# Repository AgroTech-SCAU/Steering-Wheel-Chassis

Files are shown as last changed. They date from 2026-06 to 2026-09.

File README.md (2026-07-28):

<div align="center">

# Steering-Wheel-Chassis

</div>

> AgroTech 协会中型轮式机器人代码仓库  

> 本仓库用于统一管理协会内部中型轮式机器人平台的嵌入式电控代码、Pi 端底盘通信桥、ROS2 导航系统与后续视觉 / 任务编排代码  

> 机械模型已拆分到独立仓库维护，当前仓库按“一车一目录”组织，每个一级目录代表一辆独立机器人平台，便于按车型迭代、按平台维护、按任务复用

---

## 1. 仓库定位

- 面向 AgroTech 协会中型轮式机器人平台的统一代码仓库
- 当前主要包含底盘 MCU 控制代码、Pi 端通信桥、ROS2 导航定位系统、雷达驱动、仿真与启动文件
- 适合用于舵轮底盘、五自由度机械臂、导航定位、任务状态机等整车软件链路的协同开发
- 机械模型统一维护在 [`AgroTech-SCAU/Steering-Wheel-Chassis-Model-Collection`](https://github.com/AgroTech-SCAU/Steering-Wheel-Chassis-Model-Collection)

---

## 2. 当前包含的机器人

| 机器人 | 状态 | 简介 |
| --- | --- | --- |
| `SteerWheel Mk.1` | 开发中 / 原型验证 | 初代原型机，用于验证舵轮底盘、机械臂集成、电控架构与控制算法 |
| `Atlas` | 开发中 / 导航与底盘联调 | 新一代舵轮底盘平台，当前包含 MCU 底盘控制代码、Pi 端通信桥和 ROS2 导航系统 |

另有一台尚未命名的轮式机器人正在规划中，同样采用舵轮底盘与五轴五自由度机械臂，后续会在仓库中以独立文件夹形式加入

---

## 3. 目录结构

```text
.
├─ Atlas/
│  ├─ chassis_control_code/   # MCU 端底盘控制代码，烧录到 STM32 控制板
│  ├─ chassis-pi-ws/          # 树莓派 5 ROS2 工作区，负责 MCU 通信桥接
│  ├─ navigation_system/      # ROS2 导航系统，包含雷达驱动、建图、定位、Nav2 与启动文件
│  └─ README.md
├─ SteerWheel Mk.1/
│  ├─ chassis_control_code/   # STM32H7 底盘 / 机械臂嵌入式控制代码
│  └─ README.md
└─ README.md
```

---

## 4. `SteerWheel Mk.1` 简介

`SteerWheel Mk.1` 是本仓库较早期的原型平台，主要承担以下任务：

- 验证四舵轮底盘的机械结构与运动学控制
- 验证底盘与五自由度机械臂的一体化集成
- 验证自研 STM32H723 控制板的软件分层与设备驱动架构
- 为后续 `Atlas` 及其他轮式机器人积累电控和软件复用资产

其目录中当前主要包含：

- 基于 STM32H723 的底盘与机械臂控制固件
- 机械臂 `URDF`、`mesh`、`launch` 等开发相关资源

机器人机械模型请前往独立仓库查看：

- [`AgroTech-SCAU/Steering-Wheel-Chassis-Model-Collection`](https://github.com/AgroTech-SCAU/Steering-Wheel-Chassis-Model-Collection)

更详细的说明请见 [SteerWheel Mk.1/README.md](./SteerWheel%20Mk.1/README.md)

---

## 5. `Atlas` 简介

`Atlas` 是当前重点推进的新一代中型轮式机器人平台，采用舵轮底盘作为移动底盘，使用 STM32 控制板完成底层实时控制，使用树莓派 5 运行 ROS2 Humble 导航系统

当前 `Atlas` 已经包含三部分：

- `chassis_control_code`：MCU 端底盘控制代码，负责底盘运动控制、IMU / odom 数据组织、Pi 通信协议收发与状态机权限判断
- `chassis-pi-ws`：Pi 端 ROS2 通信桥，负责读取 MCU 的 IMU / ODOM 数据并发布 `/odom`、`/imu` 和 TF，同时订阅 `/motor_cmd_vel` 并下发 `PI_CONTROL`
- `navigation_system`：ROS2 导航系统，包含 LSLIDAR 驱动、URDF、Gazebo、Cartographer 建图 / 纯定位、Nav2 与总启动文件

`Atlas` 的运行目标是形成如下闭环：

```text
MCU 底盘控制程序
  ↓ MCU_IMU / MCU_ODOM
chassis-pi-ws
  ↓ /odom /imu /tf
navigation_system
  ↓ /cmd_vel
competition_fsm
  ↓ /motor_cmd_vel
chassis-pi-ws
  ↓ PI_CONTROL
MCU 底盘控制程序
```

更详细的说明请见 [Atlas/README.md](./Atlas/README.md)

---

## 6. 开发路线

### 6.1 已有内容

- 舵轮底盘 MCU 控制代码
- Pi 端 ROS2 通信桥
- IMU / ODOM 二进制协议解析
- `/odom`、`/imu` 与 `odom -> base_footprint` TF 发布
- `/motor_cmd_vel` 到 MCU `PI_CONTROL` 的速度下发链路
- ROS2 Humble 导航系统
- Cartographer 2D 建图与纯定位
- Nav2 全局规划与局部控制
- LSLIDAR N10P 雷达驱动
- Gazebo 仿真启动文件

### 6.2 计划加入

- 更完整的 `competition_fsm` 与 `mission_manager` 说明
- `mcu_comm_bridge` 与 `robot_startup` 的统一启动入口
- `/mcu/status` 状态话题或诊断信息
- 真实场地地图与定位配置
- 视觉感知节点
- 机械臂上层控制接口
- 系统级联调记录与故障排查文档

---

## 7. 面向协作者的建议

- 新车型请直接以一级目录形式加入，保持“一车一目录”
- 机械、电控、ROS、仿真和任务代码建议按职责拆分维护，避免单个包承担过多功能
- MCU 端、Pi 端和导航端的接口应优先通过协议文档、README 和 launch 参数保持一致
- 涉及底盘安全的接口应区分周期性 topic、一次性 service 和长期 action，避免控制语义混乱
- 合并新功能前建议至少验证 `/odom`、`/imu`、`/scan`、`/motor_cmd_vel`、TF 树和 MCU AutoPi 执行链路

---

## 8. TODO

- [ ] 完善 `Atlas/README.md` 中真实地图、串口设备、启动参数和联调流程
- [ ] 将 `chassis-pi-ws` 的 `mcu_comm_bridge` 纳入 `navigation_system/robot_startup` 的真机总启动链路
- [ ] 补充或确认 `competition_fsm`、`mission_manager` 的源码位置、接口和启动方式
- [ ] 补充 `/mcu/status` 话题或诊断接口，方便状态机读取 MCU ready / fault / estop 状态
- [ ] 修正或补齐 `at_nav2` 真机定位所需的 `map.pbstream`、`map.yaml` 和 RViz 配置
- [ ] 给 URDF 补充 `imu_link` 及其相对 `base_link` 的固定变换
- [ ] 完善 MCU 固件编译、烧录、协议版本和调试说明
- [ ] 补充真实场地导航联调记录、常见问题和验收 checklist

---

## 9. 说明

本仓库仍处于持续开发阶段，部分车型资料、启动链路、接口文档和任务代码仍可能随项目推进调整

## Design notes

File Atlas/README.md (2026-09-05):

# Atlas

Atlas 是 AgroTech 协会的中型轮式机器人平台；这个目录统一管理整车 MCU 控制程序、Pi 端 ROS2 自主任务工作区、PC 主臂遥操作 App、ASRPro 语音链路和整车通信协议文档

当前主线是智械争锋全自主区：MCU 侧触发 AutoPi，Pi 端运行 YASMIN 比赛状态机，完成 A/B 场地识别、语义导航、视觉抓取、园区放置和 DONE/FAIL 上报

## Quick Start

下面的命令按实际设备划分：`chassis-pc-ws` 只在遥操作 PC 上运行，`chassis-pi-ws` 只在树莓派的 Ubuntu 22.04 / ROS2 Humble 环境运行；不要在 PC 上用 Pi 工作区能否启动来判断树莓派部署是否完整

本 Quick Start 是从未完成的实车配置走到整场联调的执行清单，不表示仓库默认 YAML 已可直接参赛；地图、导航点、扫描位姿、ROI 和放置位姿都需要按第 5～7 步实测填写

### 1. 整车角色分工

| 端 | 目录 | 作用 |
|---|---|---|
| MCU | `chassis_control_code/` | 底盘实时控制、机械臂执行、AutoPi 状态、安全边界和串口协议 |
| Pi | `chassis-pi-ws/` | ROS2 Humble、MCU bridge、导航、视觉、YASMIN 比赛状态机 |
| PC | `chassis-pc-ws/` | 主臂遥操作和上位机调试 |
| ASRPro | `atlas_asrpro/` | 语音触发和播报相关链路 |

正式自主比赛入口在 Pi 端：

```text
Atlas/chassis-pi-ws/src/app/atlas_competition_bringup/config/competition.yaml
Atlas/chassis-pi-ws/src/app/atlas_competition_bringup/launch/competition_stack.launch.py
```

### 2. MCU 侧准备

MCU 工程位于：

```text
Atlas/chassis_control_code/
```

使用 STM32CubeMX、EIDE 或当前工程配置的工具链编译烧录上电后先确认：

- MCU 固件已烧录
- Pi 可以打开 MCU 串口，例如 `/dev/ttyACM0`、`/dev/ttyUSB0` 或固定软链接 `/dev/mcu_uart`
- MCU 能输出状态、里程计、IMU 和机械臂状态帧
- AutoPi 由 MCU 侧条件触发，Pi 端不主动强行切换 MCU 模式

### 3. PC 遥操作准备

PC 端目录：

```text
Atlas/chassis-pc-ws/
```

安装 App 的 Python 依赖并从源码启动：

```bash
cd Atlas/chassis-pc-ws
python3 -m pip install -r requirements.txt
python3 scripts/main.py
```

App 启动后扫描串口，在界面中选择“主臂串口”和“从臂 MCU 串口”，应用配置后点击“开始运行”；已经打包时也可以直接启动 `AtlasTeleop`；PC 遥操作用于手动控制和调试，不是 Pi 自主比赛栈的入口；完整说明见 `chassis-pc-ws/README.md`

### 4. Pi 端环境和依赖

Pi 端目录：

```text
Atlas/chassis-pi-ws/
```

安装依赖：

```bash
sudo apt update
sudo apt install -y \
  python3-colcon-common-extensions \
  python3-pip \
  python3-rosdep \
  python3-yaml \
  python3-opencv \
  python3-numpy \
  ros-humble-navigation2 \
  ros-humble-nav2-bringup \
  ros-humble-cartographer \
  ros-humble-cartographer-ros \
  ros-humble-xacro \
  ros-humble-robot-state-publisher \
  ros-humble-rviz2
```

安装 ROS 包依赖和 Pi 端额外 Python 依赖：

全新系统如果还没有初始化 rosdep，先执行一次（已经初始化过则跳过 `rosdep init`）：

```bash
sudo rosdep init
rosdep update
```

如果 `src/third_lib/yasmin` 不存在，先取得当前工作区使用的 YASMIN 源码版本：

```bash
cd Atlas/chassis-pi-ws
mkdir -p src/third_lib
git clone https://github.com/uleroboticsgroup/yasmin.git src/third_lib/yasmin
git -C src/third_lib/yasmin checkout f28363379d9661e1c6048e304427488ee903be2c
```

```bash
cd Atlas/chassis-pi-ws
source /opt/ros/humble/setup.bash
rosdep install --from-paths src --ignore-src -r -y
python3 -m pip install --user -r requirements.txt
python3 -c "import onnxruntime; print(onnxruntime.__version__)"
test -f src/third_lib/yasmin/yasmin/package.xml
```

`vison_topic` 运行 ONNX 模型时直接导入 `onnxruntime`，该依赖没有可靠的 Humble rosdep 键，因此由工作区根目录的 `requirements.txt` 明确管理；比赛状态机还依赖固定版本的 YASMIN 源码；最后一条检查失败时，不要继续编译；依赖和配置准备完成后再执行第 8 步整包编译

### 5. 放入 A/B 半场地图

需要准备两套独立半场地图资源；导航 backend 会在视觉判断出 A/B 后，只启动对应半场的地图和定位栈

```text
arena_A.yaml
arena_A.pgm 或 arena_A.png
arena_A.pbstream

arena_B.yaml
arena_B.pgm 或 arena_B.png
arena_B.pbstream
```

地图可以放在仓库内，例如：

```text
Atlas/chassis-pi-ws/src/nav_system/at_nav2/maps/
```

也可以放在外部目录，然后在 `competition.yaml` 中使用绝对路径引用

### 6. 确认视觉和手眼标定

顶层 `competition.yaml` 管比赛场地、导航点、视觉扫描位姿、分拣 ROI 和放置位姿；相机内参和手眼矩阵属于 Pi 端视觉标定资产，当前由 `handeye_bridge` 单独加载：

```text
Atlas/chassis-pi-ws/src/vision_system/handeye_bridge/config/camera_intrinsics.yaml
Atlas/chassis-pi-ws/src/vision_system/handeye_bridge/config/samples_result.yaml
Atlas/chassis-pi-ws/src/vision_system/handeye_bridge/config/bridge_node.yaml
```

`samples_result.yaml` 保存当前 eye-in-hand 矩阵，运行时按 `^gripper T_camera` 使用；`bridge_node.yaml` 通过 `handeye_result_file: "samples_result.yaml"` 指向它；更换相机、镜头、分辨率、安装位或末端工具后，需要重新标定并替换 `camera_intrinsics.yaml` / `samples_result.yaml`，然后在第 8 步重新编译并重启

抓取高度、手动补偿和自动发送开关仍在 `bridge_node.yaml` 中确认：

```yaml
plane1_z_m: 0.031
plane2_z_m: 0.07
plane3_z_m: 0.109
manual_offset_x_m: -0.055
manual_offset_y_m: 0.000
manual_offset_z_m: 0.000
auto_send: true
```

新矩阵首次上车时建议先把 `auto_send` 设为 `false`，只看日志中的像素到基座坐标计算结果；空载验证安全后再打开自动发送

### 7. 配置唯一比赛 YAML

正式比赛优先只改这一份：

```text
Atlas/chassis-pi-ws/src/app/atlas_competition_bringup/config/competition.yaml
```

必须填入并打开对应安全门：

| 配置段 | 内容 |
|---|---|
| `competition.navigation.arenas.A` | A 半场 `map`、`pbstream`、`pickup / park_1 / park_2` 坐标 |
| `competition.navigation.arenas.B` | B 半场 `map`、`pbstream`、`pickup / park_1 / park_2` 坐标 |
| `competition.vision.sorting_scan_a/b` | 机械臂判断 A/B 的两个视觉扫描位姿 |
| `competition.vision.sorting_rule` | `park_1_roi`、`park_2_roi` 分拣标识 ROI |
| `competition.manipulation.placement` | `park_1 / park_2` 放置基准位姿、层高、slot 偏移 |

未实测字段保持：

```yaml
configured: false
enabled: false
```

地图路径为空、waypoint 未配置、扫描位姿未配置、ROI 未启用或放置未启用时，backend 会拒绝执行，不会把 0 默认值当作真实目标

### 8. 完成配置后编译 Pi 工作区

```bash
cd Atlas/chassis-pi-ws
source /opt/ros/humble/setup.bash
colcon build --symlink-install
source install/setup.bash
```

包内 `competition.yaml` 和标定 YAML 会安装到 `install/`；修改源码目录中的这些文件后必须重新编译；若使用下一步的 `competition_config:=/绝对路径/competition.yaml` 传入外部比赛配置，则该外部文件本身不需要重新编译

### 9. 启动整场比赛栈

```bash
cd Atlas/chassis-pi-ws
source /opt/ros/humble/setup.bash
source install/setup.bash
ros2 launch atlas_competition_bringup competition_stack.launch.py
```

使用外部比赛配置：

```bash
ros2 launch atlas_competition_bringup competition_stack.launch.py \
  competition_config:=/path/to/competition.yaml
```

常用联调参数：

```bash
ros2 launch atlas_competition_bringup competition_stack.launch.py --show-args

ros2 launch atlas_competition_bringup competition_stack.launch.py \
  no_preview:=true

ros2 launch atlas_competition_bringup competition_stack.launch.py \
  enable_navigation:=false \
  enable_vision:=false \
  enable_manipulation:=false \
  enable_mission:=false
```

### 10. 状态检查

```bash
ros2 topic echo /mcu/status
ros2 topic echo /atlas/mission/status
ros2 topic echo /atlas/navigation/status
ros2 topic echo /atlas/manipulation/status
ros2 topic hz /odom
ros2 topic hz /scan
```

视觉和手眼联调时重点看：

```bash
ros2 topic echo /initial_pose_ready
ros2 topic echo /vision_pose_ready
ros2 topic echo /detection_centers
ros2 topic echo /arm/pose
```

`/pick_target` 会触发 handeye_bridge 计算抓取目标；当前 `auto_send: true` 时还会向 `/mcu/set_arm_pose` 发送机械臂目标，联调前确认机械臂作业空间安全

关键服务：

```bash
ros2 service list | grep atlas
ros2 service list | grep move_to_sorting
ros2 service list | grep mcu
```

### 11. 整车执行链路

```text
ASRPro / 遥控器 / MCU 条件触发
  ↓
MCU 进入 AutoPi 并向 Pi 发布自动任务事件
  ↓
Pi 端 atlas_mission_yasmin 启动比赛任务
  ↓
vision backend 调用 handeye_bridge 扫描 sorting_scan_A / sorting_scan_B
  ↓
识别 arena=A/B 和 park_1/park_2 的货物映射
  ↓
atlas_nav_full_backend 锁定 A/B 并启动对应半场 map/pbstream
  ↓
YASMIN 只发送 pickup / park_1 / park_2 语义点
  ↓
导航到 pickup，视觉定位并抓取
  ↓
按分拣规则导航到 park_1 或 park_2
  ↓
机械臂按 placement 配置放置
  ↓
8 件完成后通过 MCU 上报 DONE；异常时上报 FAIL
```

## 目录结构

```text
Atlas/
├── atlas_asrpro/                  # ASRPro 语音链路
├── chassis_control_code/          # MCU 底盘与机械臂控制工程
├── chassis-pc-ws/                 # PC 主臂遥操作 App
├── chassis-pi-ws/                 # Pi 端 ROS2 自主任务工作区
├── docs/                          # 整车通信协议和说明文档
└── README.md
```

Pi 端核心目录：

```text
chassis-pi-ws/src/
├── app/
│   ├── atlas_competition_bringup/
│   ├── atlas_competition_config/
│   ├── atlas_competition_manipulation_backend/
│   ├── atlas_competition_vision_backend/
│   ├── atlas_mission_interfaces/
│   └── atlas_mission_yasmin/
├── mcu_comm_bridge/
├── nav_system/
│   ├── at_nav2/
│   ├── atlas_nav_full_backend/
│   ├── atlas_nav_pseudo_backend/
│   └── robot_startup/
└── vision_system/
    ├── handeye_bridge/
    ├── vison_topic/
    └── vison_topic_interfaces/
```

## 关键模块

| 模块 | 作用 |
|---|---|
| `chassis_control_code` | MCU 实时控制、状态机、安全边界和串口协议 |
| `chassis-pc-ws` | PC 主臂遥操作输入和调试 |
| `atlas_asrpro` | 语音触发与播报链路 |
| `mcu_comm_bridge` | MCU 与 ROS2 的串口桥接，发布 `/odom`、`/imu`、机械臂状态并接收控制命令 |
| `atlas_mission_yasmin` | 比赛任务状态机，负责 8 件货物循环、分类规则应用和任务编排 |
| `atlas_competition_bringup` | 正式比赛统一启动入口，安装顶层 `competition.yaml` |
| `atlas_competition_config` | 顶层 YAML 解析、A/B arena 锁定和语义 waypoint 解析 |
| `atlas_nav_full_backend` | Nav2 完整导航后端，按 `arena + waypoint_id` 解析真实 map 坐标 |
| `at_nav2` | Cartographer 纯定位、map_server 和 Nav2 bringup |
| `handeye_bridge` | 检测像素到机械臂坐标转换、抓取目标发布和视觉扫描位姿控制 |
| `vison_topic` | ONNX 目标检测服务，包名保持现有拼写 |
| `atlas_competition_vision_backend` | 识别 A/B 与分拣规则，提供比赛视觉服务 |
| `atlas_competition_manipulation_backend` | 执行观察、抓取和放置动作 |

## 主要接口

MCU 与任务触发：

```text
/mcu/status
/mcu/auto_task_event
/mcu/report_mission_result
/mcu/estop
```

底盘与传感器：

```text
/odom
/imu
/scan
/tf
/tf_static
/motor_cmd_vel
```

导航：

```text
/atlas/navigation/start
/atlas/navigation/cancel
/atlas/navigation/status
/atlas/navigation/cmd_vel
```

视觉和手眼：

```text
/vision_detect
/detection_centers
/pick_target
/move_to_initial_pose
/move_to_sorting_scan_a
/move_to_sorting_scan_b
/initial_pose_ready
/vision_pose_ready
/atlas/vision/classify_sorting_rule
/atlas/vision/detect_target
```

机械臂：

```text
/arm/joint_states
/arm/pose
/arm/pose_position
/atlas/manipulation/start
/atlas/manipulation/cancel
/atlas/manipulation/status
/mcu/set_arm_pose
/mcu/set_arm_position
/mcu/set_suction
```

## A/B 地图与导航配置

A/B 两套半场地图是必须的；`atlas_nav_full_backend` 在第一次有效导航请求时锁定 arena，并用该 arena 的 `map` 和 `pbstream` 启动导航栈

`competition.yaml` 示例：

```yaml
competition:
  navigation:
    coordinate_mode: absolute_map
    arenas:
      A:
        map: "/path/to/arena_A.yaml"
        pbstream: "/path/to/arena_A.pbstream"
        waypoints:
          pickup: {x: 1.0, y: 0.0, yaw: 0.0, configured: true}
          park_1: {x: 2.0, y: 0.4, yaw: 1.57, configured: true}
          park_2: {x: 2.0, y: -0.4, yaw: -1.57, configured: true}
      B:
        map: "/path/to/arena_B.yaml"
        pbstream: "/path/to/arena_B.pbstream"
        waypoints:
          pickup: {x: 1.0, y: 0.0, yaw: 0.0, configured: true}
          park_1: {x: 2.0, y: 0.4, yaw: 1.57, configured: true}
          park_2: {x: 2.0, y: -0.4, yaw: -1.57, configured: true}
```

相对路径会按 `competition.yaml` 所在目录解析；绝对路径原样使用

## MCU 串口配置

Pi 端 MCU 通信配置文件：

```text
Atlas/chassis-pi-ws/src/mcu_comm_bridge/config/mcu_comm_bridge.yaml
```

常见串口设备：

```text
/dev/ttyACM0
/dev/ttyUSB0
/dev/mcu_uart
```

建议通过 udev 固定软链接：

```text
SUBSYSTEM=="tty", ATTRS{idVendor}=="0483", ATTRS{idProduct}=="5740", SYMLINK+="mcu_uart", GROUP="dialout", MODE="0660"
```

应用规则并检查权限：

```bash
sudo udevadm control --reload-rules
sudo udevadm trigger
sudo usermod -aG dialout $USER
ls -l /dev/mcu_uart
```

通信协议说明见：

```text
Atlas/docs/comms_protocol.md
```

## 实车配置顺序

1. 烧录 MCU，并确认 Pi 串口连接正常
2. 启动 `mcu_comm_bridge`，确认 `/mcu/status`、`/odom`、`/imu`、`/arm/pose` 有数据
3. 启动雷达，确认 `/scan` 有数据且 TF 链路正确
4. 建 A/B 两套半场地图，保存各自 `.yaml`、地图图片和 `.pbstream`
5. 在 A/B 地图中实测 `pickup`、`park_1`、`park_2` 的 `x / y / yaw`
6. 实测 `sorting_scan_a`、`sorting_scan_b` 机械臂观察位姿
7. 配置并验证分拣标识 ROI
8. 实测 `park_1`、`park_2` 放置基准位姿、层高和四个 slot 偏移
9. 逐项把对应 `configured` 或 `enabled` 改为 `true`，再启动整场比赛栈

## 验证命令

构建 Pi 端工作区：

```bash
cd Atlas/chassis-pi-ws
source /opt/ros/humble/setup.bash
colcon build --symlink-install
source install/setup.bash
```

构建比赛相关包：

```bash
colcon build --packages-select \
  atlas_competition_config \
  atlas_nav_full_backend \
  atlas_competition_vision_backend \
  atlas_competition_manipulation_backend \
  handeye_bridge \
  atlas_competition_bringup
```

运行核心测试：

```bash
export PYTHONPATH=$PWD/src/app/atlas_competition_config:$PYTHONPATH
export PYTHONPATH=$PWD/src/app/atlas_competition_vision_backend:$PYTHONPATH
export PYTHONPATH=$PWD/src/app/atlas_competition_manipulation_backend:$PYTHONPATH
export PYTHONPATH=$PWD/src/nav_system/atlas_nav_full_backend:$PYTHONPATH
export PYTHONPATH=$PWD/src/vision_system/handeye_bridge:$PYTHONPATH

python3 -m pytest \
  src/app/atlas_competition_config/test/test_config.py \
  src/app/atlas_competition_vision_backend/test/test_backend.py \
  src/app/atlas_competition_manipulation_backend/test/test_manipulation_config.py \
  src/nav_system/atlas_nav_full_backend/test/test_competition_navigation.py \
  src/vision_system/handeye_bridge/test/test_vision_pose_gate.py
```

解析比赛 launch 参数：

```bash
ROS_LOG_DIR=/tmp/atlas_ros_log \
ros2 launch atlas_competition_bringup competition_stack.launch.py --show-args
```

## 安全原则

- Pi 不主动请求 MCU 进入 AutoPi；自动任务由 MCU 侧条件触发
- Nav2 速度先进入 `/atlas/navigation/cmd_vel`，再经任务安全门控输出到 `/motor_cmd_vel`
- 顶层 `competition.yaml` 默认保持安全拒绝状态
- 未确认地图、坐标、机械臂位姿、ROI 或放置点之前，不开启对应 `configured/enabled`
- A/B arena 一场比赛只锁定一次，不允许运行中切换半场地图
- 急停、刹车、串口离线和 MCU 状态异常优先由 MCU/Pi 安全链处理

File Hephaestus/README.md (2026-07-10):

<div align="center">

# Atlas

</div>

> `Atlas` 是 AgroTech 协会新一代中型轮式机器人平台  
> 当前目录用于统一管理 Atlas 的 MCU 底盘控制代码、PC 主臂遥操作脚本、树莓派 Pi 端通信桥、ROS2 导航系统，以及仿真与真机联调链路

---

## 1. 平台定位

`Atlas` 面向中型轮式机器人平台，目标是形成一套可用于比赛、实验和后续研究的整车软件系统

当前软件链路可以分为四层：

```text
PC 主臂 teleop / 上位机调试
        ->
ROS2 导航系统 / 状态机 / 上层任务
        ->
树莓派 5 chassis-pi-ws 通信桥
        ->
MCU 底盘实时控制程序
        ->
轮式底盘 / IMU / 电机 / 编码器 / 机械臂
```

其中：

- MCU 端负责底盘实时控制、IMU 与里程计组织、PC/Pi 协议解析、应用状态机与安全边界控制
- Pi 端负责把 MCU 数据转换为 ROS2 话题，并把 ROS2 控制命令转换为 MCU 协议帧
- ROS2 端负责雷达驱动、建图、定位、路径规划、速度输出以及导航链路编排
- PC 端负责主臂遥操作输入，并通过串口向 MCU 下发 `PC_MASTER_JOINTS` 与 `PC_HEARTBEAT`

---

## 2. 目录结构

```text
Atlas/
├── chassis_control_code/
│   ├── arm_description/           # Atlas 底盘与机械臂模型
│   ├── src/                       # MCU 端底层控制代码
│   └── robot.ioc                  # STM32CubeMX 工程
│
├── chassis-pi-ws/
│   ├── src/
│   │   └── mcu_comm_bridge/       # Pi 端 ROS2 <-> MCU 通信桥
│   └── README.md
│
├── chassis-pc-ws/
│   ├── scripts/
│   │   └── teleop.py              # PC 主臂遥操作脚本
│   └── README.md
│
├── chassis-pi-ws/src/nav_system/
│   ├── at_nav2/                   # Nav2 导航栈与 Cartographer 纯定位启动
│   ├── atlas_nav_full_backend/    # 任务状态机使用的完整导航后端适配器
│   ├── atlas_nav_pseudo_backend/  # 伪导航后端，用于安全联调
│   └── README.md
│
├── chassis-pi-ws/src/vision_system/
│   ├── racom_vision/              # RACOM 视觉适配层，默认替换旧视觉模型
│   ├── raicom_vsion/              # 原 RACOM/RAICOM 检测服务源码目录
│   ├── atlas_vision_pollination_backend/ # 动作序列、手眼变换和作业后端
│   └── README.md
│
├── docs/
│   └── comms_protocol.md          # PC / Pi / MCU 统一通信协议说明
│
└── README.md
```

---

## 3. 系统功能

### 3.1 MCU 底盘控制

`chassis_control_code` 是烧录到 MCU 控制板中的底层控制程序

它主要负责：

- 接收 PC 端 `PC_HEARTBEAT`、`PC_MASTER_JOINTS`
- 接收 Pi 端 `PI_CONTROL`、`PI_ARM_ACTION`、`PI_YAW_ACTION`、`PI_ESTOP`、`PI_ACK`
- 执行底盘速度控制、机械臂控制、yaw hold 与任务事件消费
- 周期性发布 `MCU_IMU`、`MCU_ODOM`、`MCU_ARM_STATE`、`MCU_STATUS`
- 维护 PC/Pi 在线状态、fresh timeout、急停、故障与应用状态机权限边界

当前关键 MCU -> 上位机数据帧：

```text
MCU_STATUS      0x21   5~10Hz   app_state / ready_flags / online_flags / fault
MCU_IMU         0x25   100Hz    acc_x/y/z + gyro_x/y/z + roll/pitch/yaw
MCU_ODOM        0x26   50Hz     x/y/yaw + vx/vy/wz
MCU_ARM_STATE   0x27   50Hz     q0~q4 + pose(xyz + quat xyzw) + status_flags
```

当前关键上位机 -> MCU 控制帧：

```text
PC_HEARTBEAT     0x10
PC_MASTER_JOINTS 0x11
PI_HEARTBEAT     0x30
PI_CONTROL       0x31
PI_ARM_ACTION    0x40
PI_YAW_ACTION    0x41
PI_MISSION_EVENT 0x42
PI_ESTOP         0x43
PI_ACK           0x44
```

---

### 3.2 Pi 端底盘通信桥

`chassis-pi-ws` 运行在树莓派 5 上，是 ROS2 导航系统和 MCU 底盘控制程序之间的通信桥

它主要负责：

- 通过串口连接 MCU
- 解析 MCU 二进制协议帧
- 将 `MCU_ODOM` 发布为 `/odom`
- 将 `MCU_IMU` 发布为 `/imu`
- 将 `MCU_ARM_STATE` 发布为 `/arm/joint_states`、`/arm/pose` 与 `/arm/pose_position`
- 根据 MCU 里程计发布 `odom -> base_footprint` TF
- 订阅状态机仲裁后的 `/motor_cmd_vel`
- 将 `/motor_cmd_vel` 转换为 `PI_CONTROL` 并周期性下发给 MCU
- 通过 service 下发刹车、急停、yaw hold、yaw target 等一次性命令

Pi 端对外提供的主要 ROS2 接口：

| 接口 | 类型 | 方向 | 说明 |
| --- | --- | --- | --- |
| `/odom` | `nav_msgs/msg/Odometry` | 发布 | 底盘局部里程计，供 Cartographer 和 Nav2 使用 |
| `/imu` | `sensor_msgs/msg/Imu` | 发布 | MCU IMU 与融合姿态数据 |
| `/arm/joint_states` | `sensor_msgs/msg/JointState` | 发布 | 机械臂 q0~q4 当前关节角 |
| `/arm/pose` | `geometry_msgs/msg/PoseStamped` | 发布 | MCU 正运动学求得的末端位姿，四元数顺序为 `x/y/z/w` |
| `/arm/pose_position` | `geometry_msgs/msg/PointStamped` | 发布 | 机械臂末端位置话题，与 `/arm/pose` 的 `pose.position` 同源 |
| `odom -> base_footprint` | TF | 发布 | 底盘局部 TF |
| `/motor_cmd_vel` | `geometry_msgs/msg/Twist` | 订阅 | 状态机仲裁后的底盘速度指令 |
| `/mcu/set_brake` | `std_srvs/srv/SetBool` | service | 设置或解除底盘刹车 |
| `/mcu/estop` | `mcu_comm_bridge/srv/Estop` | service | 向 MCU 发送急停事件 |
| `/mcu/set_yaw_hold` | `std_srvs/srv/SetBool` | service | 开启或关闭 MCU 侧 yaw hold |
| `/mcu/set_yaw_target` | `mcu_comm_bridge/srv/SetYawTarget` | service | 设置 MCU 侧目标 yaw |
| `/mcu/set_suction` | `std_srvs/srv/SetBool` | service | PI 端条件控制末端吸盘，默认要求 MCU 处于 AutoPi |

---

### 3.3 PC 主臂遥操作链路

`chassis-pc-ws` 用于运行 PC 端主臂遥操作脚本，目前以单脚本方式工作

它主要负责：

- 连接主臂 Dynamixel 串口
- 周期性读取主臂 q0~q4 与末端开关状态
- 将主臂角度打包为 `PC_MASTER_JOINTS`
- 向 MCU 周期性发送 `PC_HEARTBEAT`
- 为机械臂手动跟随、调试和主从控制提供输入链路

典型 PC -> MCU 遥操作链路：

```text
PC teleop
  -> PC_MASTER_JOINTS / PC_HEARTBEAT
MCU
  -> app_fsm / manual mode permission check
机械臂执行层
```

---

### 3.4 ROS2 导航系统

`chassis-pi-ws/src/nav_system` 是 Atlas 的 ROS2 导航与整车启动目录，基于 ROS2 Humble、Cartographer 2D 和 Nav2 构建

它主要负责：

- 启动 LSLIDAR N10P 雷达驱动并发布 `/scan`
- 启动 URDF 模型和 `robot_state_publisher`
- 使用 Cartographer 进行 2D 建图或纯定位
- 使用 Nav2 完成全局规划和局部控制
- 通过 `atlas_mission_manager` 对 Nav2 输出速度进行任务级安全门控
- 将门控后的最终速度指令发布到 `/motor_cmd_vel`

典型导航控制链路：

```text
LSLIDAR
  -> /scan
Cartographer / Nav2

MCU
  -> MCU_ODOM
chassis-pi-ws
  -> /odom + odom -> base_footprint
Cartographer / Nav2

Nav2 controller_server
  -> /cmd_vel remap 到 /atlas/navigation/cmd_vel
atlas_mission_manager
  -> /motor_cmd_vel
mcu_comm_bridge
  -> PI_CONTROL
MCU
```

---

### 3.5 当前 PI 端默认任务链路

本版本中，PI 端任务系统默认使用完整导航后端和 `racom_vision`：

```text
/mcu_comm_bridge
  -> /odom, /imu, /arm/joint_states, /arm/pose

at_nav2
  -> Cartographer 纯定位
  -> Nav2 navigation_launch
  -> /atlas/navigation/cmd_vel

atlas_nav_full_backend
  -> /atlas/navigation/start
  -> Nav2 NavigateToPose
  -> /atlas/navigation/status

atlas_mission_manager
  -> 根据任务阶段把 /atlas/navigation/cmd_vel 门控到 /motor_cmd_vel

racom_vision + atlas_racom_vision_backend
  -> /vision_detect
  -> /vision/detect_camera_target

atlas_vision_pollination_backend
  -> 复用原动作序列、手眼变换和机械臂服务
  -> 必要时通过 /mcu/set_suction 或机械臂服务附带字段控制吸盘
```

推荐总启动：

```bash
source ~/chassis-pi-ws/install/setup.bash
ros2 launch atlas_mission_manager mission_stack.launch.py
```

可选回退：

```bash
# 不启动 Nav2，只做任务状态机安全联调
ros2 launch atlas_mission_manager mission_stack.launch.py navigation_backend:=pseudo

# 回退旧视觉目标服务
ros2 launch atlas_mission_manager mission_stack.launch.py manipulation_backend:=vision_pollination
```

PI 端吸盘控制默认要求 MCU 处于 `AutoPi`：

```bash
ros2 service call /mcu/set_suction std_srvs/srv/SetBool "{data: true}"
ros2 service call /mcu/set_suction std_srvs/srv/SetBool "{data: false}"
```

---

## 4. 环境要求

推荐运行环境：

```text
树莓派 5
Ubuntu 22.04
ROS2 Humble
```

建议安装的 ROS2 组件：

```bash
sudo apt update
sudo apt install -y \
  python3-colcon-common-extensions \
  python3-rosdep \
  ros-humble-desktop \
  ros-humble-navigation2 \
  ros-humble-nav2-bringup \
  ros-humble-cartographer \
  ros-humble-cartographer-ros \
  ros-humble-gazebo-ros-pkgs \
  ros-humble-xacro \
  ros-humble-robot-state-publisher \
  ros-humble-joint-state-publisher-gui \
  ros-humble-rviz2 \
  libpcap-dev \
  libpcl-dev
```

如果是第一次使用 `rosdep`：

```bash
sudo rosdep init
rosdep update
```

---

## 5. 编译

Atlas 当前包含多个子工作区，通常按模块分别编译

### 5.1 Pi 端工作区

```bash
cd ~/chassis-pi-ws
rosdep install --from-paths src --ignore-src -r -y
colcon build --symlink-install
source install/setup.bash
```

如果修改了 service 文件，例如 `Estop.srv`、`SetYawTarget.srv` 或 `SetArmJoints/SetArmPose/SetArmPosition/SetArmOrientation.srv`，建议清理后重新编译：

```bash
rm -rf build install log
colcon build --symlink-install
source install/setup.bash
```

### 5.2 导航与任务包

导航、任务状态机、视觉适配器和 MCU 通信桥都位于 `chassis-pi-ws/src` 下。常规情况下只需要编译 PI 端工作区即可。

### 5.3 MCU 工程

`chassis_control_code` 为 STM32 工程，通常通过 STM32CubeMX / EIDE / 对应工具链进行编译与烧录

---

## 6. MCU 串口与协议配置

当前建议优先使用 USB 虚拟串口或 USB-TTL 模块，而不是树莓派 GPIO UART

常见设备名：

```text
/dev/ttyACM0   # STM32 USB CDC 常见设备名
/dev/ttyUSB0   # USB-TTL 常见设备名
/dev/mcu_uart  # 建议通过 udev 固定后的设备名
```

建议为 MCU 串口创建固定软链接：

```bash
sudo nano /etc/udev/rules.d/99-mcu-uart.rules
```

示例规则：

```text
SUBSYSTEM=="tty", ATTRS{idVendor}=="0483", ATTRS{idProduct}=="5740", SYMLINK+="mcu_uart", GROUP="dialout", MODE="0660"
```

重新加载规则：

```bash
sudo udevadm control --reload-rules
sudo udevadm trigger
```

将当前用户加入串口权限组：

```bash
sudo usermod -aG dialout $USER
```

重新登录或重启后检查：

```bash
ls -l /dev/mcu_uart
groups
```

完整协议说明见：

```text
docs/comms_protocol.md
```

---

## 7. Pi 端桥接节点使用方法

单独启动 MCU 通信桥：

```bash
source ~/chassis-pi-ws/install/setup.bash
ros2 launch mcu_comm_bridge mcu_comm_bridge.launch.py
```

临时指定串口：

```bash
ros2 run mcu_comm_bridge mcu_comm_bridge_node --ros-args \
  -p port:=/dev/ttyUSB0 \
  -p baudrate:=1000000
```

推荐配置文件位置：

```text
chassis-pi-ws/src/mcu_comm_bridge/config/mcu_comm_bridge.yaml
```

常用参数：

| 参数 | 默认值 | 说明 |
| --- | --- | --- |
| `port` | `/dev/ttyUSB0` | MCU 串口设备 |
| `baudrate` | `1000000` | 串口波特率 |
| `odom_topic` | `/odom` | 里程计话题 |
| `imu_topic` | `/imu` | IMU 话题 |
| `cmd_vel_topic` | `/motor_cmd_vel` | 底盘速度输入话题 |
| `arm_joint_state_topic` | `/arm/joint_states` | 机械臂关节状态话题 |
| `arm_pose_topic` | `/arm/pose` | 机械臂末端位姿话题 |
| `arm_pose_position_topic` | `/arm/pose_position` | 机械臂末端位置话题 |
| `odom_frame_id` | `odom` | odom 坐标系 |
| `base_frame_id` | `base_footprint` | 底盘基座坐标系 |
| `imu_frame_id` | `imu_link` | IMU 坐标系 |
| `arm_frame_id` | `arm_base_link` | 机械臂参考坐标系 |
| `publish_tf` | `true` | 是否发布 `odom -> base_footprint` |
| `control_rate_hz` | `50.0` | `PI_CONTROL` 下发频率 |
| `cmd_vel_timeout_ms` | `200` | 底盘速度指令超时时间 |

---

## 8. PC 端遥操作使用方法

PC 端说明见：

```text
chassis-pc-ws/README.md
```

典型运行方式：

```bash
python3 teleop.py \
  --leader-port /dev/ttyUSB0 \
  --mcu-port /dev/ttyUSB1 \
  --freq 50
```

仅调试主臂输入、不向 MCU 发包：

```bash
python3 teleop.py \
  --leader-port /dev/ttyUSB0 \
  --dry-run \
  --print-rate 10
```

使用前建议先确认：

- 主臂 Dynamixel 端口可正常打开
- MCU 串口与波特率匹配
- `PC_MASTER_JOINTS` 的 payload 长度与 MCU 解析实现一致

---

## 9. 导航系统使用方法

### 9.1 仿真启动

启动 Gazebo 仿真：

```bash
source ~/chassis-pi-ws/install/setup.bash
ros2 launch robot_gazebo gazebo_sim.launch.py
```

启动仿真导航：

```bash
source ~/chassis-pi-ws/install/setup.bash
ros2 launch at_nav2 at_nav_gazebo.launch.py
```

### 9.2 建图

启动仿真或真机传感器后，运行 Cartographer 建图：

```bash
source ~/chassis-pi-ws/install/setup.bash
ros2 launch robot_cartographer_mapping robot_cartographer_mapping_gazebo.launch.py
```

保存 Cartographer 状态：

```bash
ros2 service call /write_state cartographer_ros_msgs/srv/WriteState \
  "{filename: '$(pwd)/map.pbstream'}"
```

导出 Nav2 使用的地图：

```bash
ros2 run nav2_map_server map_saver_cli -t map -f map
```

### 9.3 真机启动

真机启动前应确认：

- MCU 已烧录并上电
- Pi 能打开 MCU 串口
- 雷达设备已连接
- 地图文件已放到 `at_nav2/maps/`
- `atlas_mission_manager`、`atlas_nav_full_backend`、`atlas_racom_vision_backend` 在工作区中可用
- MCU 已进入允许 Pi 控制的 `AutoPi` 状态

启动整车系统：

```bash
source ~/chassis-pi-ws/install/setup.bash
ros2 launch robot_startup robot_start.launch.py
```

当前 `robot_startup` 已纳入 `mcu_comm_bridge`、雷达、机器人模型和任务总栈。如果只分步调试，可单独启动对应 launch。

---

## 10. 联调检查

### 10.1 检查话题

```bash
ros2 topic list
```

至少应看到：

```text
/scan
/odom
/imu
/arm/joint_states
/arm/pose
/arm/pose_position
/atlas/navigation/cmd_vel
/motor_cmd_vel
/tf
/tf_static
```

检查频率：

```bash
ros2 topic hz /odom
ros2 topic hz /imu
ros2 topic hz /arm/joint_states
ros2 topic hz /arm/pose
ros2 topic hz /arm/pose_position
ros2 topic hz /scan
```

期望：

```text
/odom 约 50Hz
/imu 约 100Hz
/arm/joint_states 约 50Hz
/arm/pose 约 50Hz
/arm/pose_position 约 50Hz
/scan 按雷达配置输出
```

### 10.2 检查 TF

```bash
ros2 run tf2_ros tf2_echo odom base_footprint
ros2 run tf2_ros tf2_echo base_link laser_link
```

完整 TF 链路应为：

```text
map -> odom -> base_footprint -> base_link -> laser_link
```

### 10.3 检查底盘控制下发

手动发布速度：

```bash
ros2 topic pub /motor_cmd_vel geometry_msgs/msg/Twist \
  "{linear: {x: 0.1, y: 0.0, z: 0.0}, angular: {x: 0.0, y: 0.0, z: 0.0}}"
```

如果 MCU 已进入 `AutoPi` 状态，底盘应执行对应速度

### 10.4 检查机械臂状态

```bash
ros2 topic echo /arm/joint_states
ros2 topic echo /arm/pose
ros2 topic echo /arm/pose_position
```

如果没有数据，优先检查 MCU 是否已发送 `MCU_ARM_STATE(0x27)`

### 10.5 检查 service

刹车：

```bash
ros2 service call /mcu/set_brake std_srvs/srv/SetBool "{data: true}"
```

解除刹车：

```bash
ros2 service call /mcu/set_brake std_srvs/srv/SetBool "{data: false}"
```

开启 yaw hold：

```bash
ros2 service call /mcu/set_yaw_hold std_srvs/srv/SetBool "{data: true}"
```

设置目标 yaw：

```bash
ros2 service call /mcu/set_yaw_target mcu_comm_bridge/srv/SetYawTarget "{yaw_rad: 1.57}"
```

急停：

```bash
ros2 service call /mcu/estop mcu_comm_bridge/srv/Estop "{reason: 1}"
```

---

## 11. 当前注意事项

- `chassis-pi-ws` 默认订阅 `/motor_cmd_vel`，不是 `/cmd_vel`
- 完整任务链路中 Nav2 的 `/cmd_vel` 已 remap 为 `/atlas/navigation/cmd_vel`，再由 `atlas_mission_manager` 门控到 `/motor_cmd_vel`
- MCU 是否执行 Pi 下发速度，最终由 MCU 状态机决定
- 普通底盘速度属于周期性控制，使用 topic + `PI_CONTROL`
- 刹车、急停、yaw hold、yaw target 属于一次性命令，使用 service
- `MCU_ARM_STATE` 已纳入协议，但真机联调时仍需确认其发布频率与字段有效位
- `odom -> base_footprint` 应由 Pi 端桥接节点发布
- `map -> odom` 应由 Cartographer 纯定位或建图节点发布
- PC 主臂输入是否生效，最终由 MCU 手动模式与权限状态决定

---

## 12. TODO

### 12.1 启动与集成

- [ ] 将 `mcu_comm_bridge` 正式纳入 `robot_startup/launch/robot_start.launch.py`
- [x] 接入 `atlas_mission_manager`、完整导航后端和 PI 端速度门控
- [x] 明确 `/cmd_vel`、`/atlas/navigation/cmd_vel`、`/motor_cmd_vel` 与底盘执行层之间的完整链路
- [ ] 确认真机启动时 `/scan`、`/odom`、`/tf` 均已在 Nav2 启动前可用

### 12.2 地图与定位

- [ ] 补齐真实场地 `map.pbstream`
- [ ] 补齐真实场地 `map.yaml` 和 `map.pgm`
- [ ] 修正 `at_nav.launch.py` 中地图文件和 RViz 文件路径
- [ ] 建立真实场地建图、保存、纯定位启动的标准流程

### 12.3 Pi 端通信桥

- [ ] 为 `SerialPort::write_all()` 增加超时保护，避免 USB 串口异常时忙等或阻塞
- [ ] 发布 `/mcu/status` 或 `diagnostic_msgs/DiagnosticArray`
- [ ] 补充 `MCU_ACK`、`MCU_STATUS` 的 ROS2 可观测性输出
- [ ] 将 MCU 时间戳与 ROS 时间戳的同步策略文档化
- [ ] 增加 rosbag 记录建议和通信统计说明

### 12.4 PC 端遥操作

- [ ] 明确 `teleop.py` 与文档中的参数、默认端口、协议版本是否完全一致
- [ ] 补充主臂关节方向、零位与夹爪阈值的标定流程
- [ ] 统一 `PC_MASTER_JOINTS` 的 payload 变更说明与 MCU 解析实现

### 12.5 机器人模型与 TF

- [ ] 在 URDF 中补全 `imu_link`
- [ ] 明确 `base_link -> imu_link` 的安装位姿
- [ ] 确认 `laser_link` 命名与雷达驱动 `frame_id` 完全一致
- [ ] 检查 `base_footprint -> base_link` 与实际底盘高度是否一致

### 12.6 MCU 端

- [ ] 补充 MCU 固件编译和烧录说明
- [ ] 补充 MCU 状态机说明，尤其是 `AutoPi` 与手动模式的进入条件
- [ ] 补充 `MCU_IMU`、`MCU_ODOM`、`MCU_ARM_STATE`、`PI_CONTROL` 的实测频率记录
- [ ] 补充 MCU 故障、急停、PC/Pi 离线处理策略说明

### 12.7 系统联调

- [ ] 建立最小闭环验收表：`/odom`、`/imu`、`/scan`、TF、`/motor_cmd_vel`、MCU 执行
- [ ] 建立真机低速测试流程
- [ ] 建立急停和刹车测试流程
- [ ] 建立 Nav2 目标点导航测试流程
- [ ] 建立常见问题排查文档

---

## 13. 总结

`Atlas` 当前已经具备 MCU 底盘控制、PC 主臂遥操作、Pi 端通信桥、完整导航后端、RACOM 视觉适配和任务状态机主线

它的最小闭环目标是打通：

```text
MCU -> /odom -> Cartographer / Nav2 -> /atlas/navigation/cmd_vel -> mission_manager -> /motor_cmd_vel -> MCU
```

同时补齐：

```text
PC teleop -> PC_MASTER_JOINTS -> MCU -> 机械臂执行
```

在完成启动整合、地图路径修正、FSM 包确认、通信观测性补强以及真机联调后，`Atlas` 就可以进入更稳定的整车闭环验证阶段

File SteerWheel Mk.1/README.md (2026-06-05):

<div align="center">

# SteerWheel Mk.1

</div>

> AgroTech 协会中型轮式机器人初代原型机

> `SteerWheel Mk.1` 用于验证舵轮底盘、五自由度机械臂、一体化电控架构和基础遥控作业流程，是后续 `Atlas` 及同类轮式机器人平台的技术试验床与资产来源

---

## 1. 项目目标

- 验证四舵轮底盘的机械方案与控制算法
- 验证中型轮式平台与五轴五自由度机械臂的整机集成
- 建立可复用的嵌入式软件分层架构
- 为后续 ROS 视觉、导航和任务执行系统预留接口与模型基础

---

## 2. 当前状态

- 机械模型：较完整，包含整车、主动万向脚轮、机械臂、PCB、场地等模型
- 嵌入式控制：已具备底盘、机械臂、IMU、遥控、RGB 指示、日志等基础能力
- ROS 上层：仓库内已有机械臂 URDF/mesh/launch 资源，但尚未形成完整 ROS 工作流
- 项目阶段：原型机验证阶段，适合作为开发底座，不建议视为最终量产方案

---

## 3. 核心特性

- 四模块舵轮底盘
- 底盘转向与驱动双总线分离控制
- 五轴五自由度机械臂
- STM32H723 主控板
- BMI088 IMU 姿态采集
- iBus 遥控链路
- WS2812 RGB 状态指示
- 机械臂 URDF/mesh 资源与基础仿真文件

---

## 4. 系统总览

### 4.1. 机械系统

本车型目录下的 `model/` 包含完整的 SolidWorks 机械资料，能看出原型机由以下几部分构成：

- 底盘主体
  - `整车.SLDASM`
  - `装配体.SLDASM`
  - `底盘玻纤板.SLDPRT`
  - `顶部玻纤板.SLDPRT`
  - `后壳.SLDPRT`
  - `挡板.SLDPRT`
  - 电池垫、黄铜柱、PCB 安装件等结构件
- 主动万向脚轮 / 舵轮模块
  - `主动万向脚轮/主动万向脚轮.SLDASM`
  - `主动万向脚轮/转向机构.SLDASM`
  - 轮组玻纤板、轴承、同步带、滑环、连接件、打印件等零件
- 机械臂
  - `机械臂/机械臂.SLDASM`
  - `机械臂底座/` 中的底座、轴承压环、固定套等
  - `机械臂A/B/C/D/E` 等连杆零件
- 板级与外设相关模型
  - `CtrBoard-H7_V1.0.SLDPRT`
  - `PCB.SLDPRT`
  - `PCB整体.SLDASM`
  - `八路灰度传感器`、`BGS301N 光电传感器` 等
- 场地/任务环境模型
  - `场地/`
  - `场地道具/`

### 4.2. 电控系统

从 `chassis_control_code/` 与 `robot.ioc` 可以确认，原型机电控核心为一块基于 `STM32H723VGT6` 的自研控制板，固件已接入如下外设：

- `FDCAN1`
  - 转向电机总线
- `FDCAN2`
  - 驱动电机总线
- `SPI2`
  - BMI088 IMU
- `SPI6`
  - WS2812 RGB 灯数据输出
- `UART5`
  - iBus 遥控接收
- `UART7`
  - 机械臂总线舵机通信
- `USART1`
  - 调试/日志串口
- `TIM6`
  - 500 Hz 控制节拍

CubeMX 工程显示主控运行在 `500 MHz`，底盘双 CAN 均配置为 `1 Mbps`

---

## 5. 硬件推断与实现说明

以下内容来自现有模型命名与代码实现，可作为当前原型机的实际设计参考：

### 5.1. 底盘驱动与转向

`src/service/assemble/assemble_chassis.c` 中可以看到：

- 转向电机接口使用 `dm_motor`
- 驱动电机接口使用 `dji_motor`
- 底盘模型参数为
  - 长：`0.26572986916 m`
  - 宽：`0.26572986916 m`
  - 轮半径：`0.057965 m`
  - 最大轮线速度：`2.0 m/s`

而在机械模型中可以看到：

- 转向侧包含 `DM-G6220`
- 驱动侧包含 `RoboMaster M3508`
- 轮组含同步带、轴承、滑环与若干打印件/碳板/玻纤板

因此可以将当前原型理解为：

- 四个舵轮模块
- 每个模块 1 个转向电机 + 1 个驱动电机
- 转向与驱动分别通过两路 CAN 独立管理

### 5.2. 机械臂

现有代码和模型表明本机机械臂为五轴五自由度方案：

- 软件运动学接口位于 `src/domain/serial_arm/`
- 服务层接口位于 `src/service/arm.c`
- 装配时通过 `assemble_arm.c` 配置 `ARM_DOF`
- URDF 与 STL 资源位于
  - `chassis_control_code/arm_description/`
  - `model/URDF_arm/ARM/`

`assemble_arm.c` 中的默认零位关节角为：

```text
Joint 1:   0.0 deg
Joint 2:  94.5 deg
Joint 3: 135.0 deg
Joint 4: -54.0 deg
Joint 5: -13.5 deg
```

机械臂控制层支持：

- 整体关节控制
- 单关节控制
- 回舵机零位
- 回 MDH 零位
- 位姿 IK 控制
- 仅位置控制
- 仅姿态控制
- 当前关节/位姿缓存读取

### 5.3. 传感器与交互

- IMU：`BMI088`
- 遥控：`FS-iA10B / iBus`
- 状态灯：`WS2812`
- 另有灰度/光电相关模型仅用于人工智能与机器人大赛，不作为协会通用平台的标配传感器

---

## 6. 软件架构

`chassis_control_code/` 采用比较清晰的分层组织：

```text
chassis_control_code/
├─ Core/                  # STM32Cube 生成入口与底层初始化
├─ src/
│  ├─ app/                # 应用层，如遥控逻辑、系统入口
│  ├─ service/            # 服务层，负责底盘/机械臂/IMU/RGB 等系统装配
│  ├─ device/             # 设备抽象层，电机、舵机、IMU、RGB、遥控接收器
│  ├─ domain/             # 领域层，舵轮底盘与串联机械臂运动学
│  ├─ infra/              # 基础设施，日志、PID、矩阵、协议解析、HFSM 等
│  └─ platform/           # STM32 HAL 适配层
├─ arm_description/       # 机械臂 ROS 描述资源
├─ robot.ioc              # STM32CubeMX 工程
└─ robot.code-workspace
```

推荐的理解顺序：

1. `Core/Src/main.c`
2. `src/app/entry.h`
3. `src/service/assemble/*.c`
4. `src/service/chassis.c` 与 `src/service/arm.c`
5. `src/domain/`
6. `src/device/` 与 `src/platform/`

---

## 7. 启动流程

固件入口在 `Core/Src/main.c`，初始化外设后调用：

```c
entry_init();
while (1) {
    entry_loop();
}
```

`entry_init()` 的装配顺序为：

1. 延时模块
2. 日志模块
3. RGB 模块
4. IMU 模块
5. 底盘模块
6. 遥控模块
7. `TIM6 500Hz`
8. 机械臂模块

这意味着系统默认就是“先完成所有底层装配，再进入统一事件循环”的结构

---

## 8. 控制循环

`TIM6` 被配置成 `500 Hz` 周期任务，`entry_loop()` 中的主要逻辑为：

- 每个 2 ms：
  - 更新 IMU
  - 执行底盘控制 `chassis.process()`
  - 每 5 个周期执行一次遥控处理 `remote_process()`
- 每 1 s：
  - 根据底盘就绪状态和遥控在线状态更新 RGB 指示灯
  - 输出心跳日志

RGB 状态约定：

- 红色：底盘未就绪
- 绿色：底盘就绪，但遥控未在线
- 蓝色：底盘就绪且遥控在线

---

## 9. 底盘控制逻辑

底盘服务主要位于 `src/service/chassis.c`，具备以下值得关注的设计：

- 四舵轮运动学正逆解
- 转向绝对角最近解选择
- 驱动反向等效解优化
- 转向 S 曲线跟踪速度规划
- “先转向再驱动”门控
- 驱动/转向反馈缺失时的自动重试上电准备
- 驻车刹车姿态控制
- 基于线速度的偏航补偿项

当前实现中还包含一套偏航补偿模型：

```text
k_vx = 0.042
k_vy = 0.028
v_deadband = 0.01
```

这说明原型机已经开始处理舵轮平台在实际运动中的偏航误差问题，而不是只停留在理想运动学层面

---

## 10. 遥控逻辑

遥控应用位于 `src/app/remote.c`，现有行为可以概括为：

- `SWA`
  - 高位：底盘控制模式
  - 低位：机械臂控制模式
- `SWB`
  - 作为快/中/慢挡速度配置
- `SWC`
  - 在底盘模式下用于制动或切换“先转向再驱动”
  - 在机械臂模式下用于不同控制子模式
- `SWD`
  - 高位时不执行控制
- `VRA / VRB`
  - 作为控制使能/保护条件

### 10.1. 底盘模式

底盘模式下支持：

- `vx / vy / wz` 全向速度控制
- 三挡速度上限切换
- 驻车制动
- 航向保持 `yaw hold`

速度上限当前配置为：

| 挡位 | `vx` | `vy` | `wz` |
| --- | --- | --- | --- |
| 快挡 | `2.0 m/s` | `2.0 m/s` | `8.0 rad/s` |
| 中挡 | `1.0 m/s` | `1.0 m/s` | `4.0 rad/s` |
| 慢挡 | `0.5 m/s` | `0.5 m/s` | `2.0 rad/s` |

### 10.2 机械臂模式

机械臂模式下支持：

- 单独控制底座偏航关节
- 控制末端前伸/回缩
- 控制末端升降
- 控制姿态 yaw
- 一键回机械臂零位

这是一个偏“原型验证型”的手动操作方案，适合调试与任务流程试验

---

## 11. 机械臂描述与仿真资源

仓库内已经放入两套相关资源：

- `model/URDF_arm/ARM/`
- `chassis_control_code/arm_description/`

包含：

- `urdf/ARM.urdf`
- `meshes/*.STL`
- `launch/display.launch`
- `launch/gazebo.launch`
- `config/joint_names_ARM.yaml`

这对后续接入 ROS 可视化、MoveIt、Gazebo 或其他上层系统非常有帮助

---

## 12. 目录说明

### 12.1. 机械资料

- [model](./model)
  - 整车、底盘、舵轮、机械臂、板级与场地模型

### 12.2. 嵌入式代码

- [chassis_control_code](./chassis_control_code)
  - STM32H723 固件工程
- [robot.ioc](./chassis_control_code/robot.ioc)
  - STM32CubeMX 配置
- [Core/Src/main.c](./chassis_control_code/Core/Src/main.c)
  - 固件入口

### 12.3. 关键源码位置

- [src/app/entry.h](./chassis_control_code/src/app/entry.h)
- [src/app/remote.c](./chassis_control_code/src/app/remote.c)
- [src/service/chassis.c](./chassis_control_code/src/service/chassis.c)
- [src/service/arm.c](./chassis_control_code/src/service/arm.c)
- [src/service/assemble/](./chassis_control_code/src/service/assemble)
- [src/domain/](./chassis_control_code/src/domain)

---

## 13. 开发环境

当前工程适合以下工具链：

- `STM32CubeMX`
- `STM32CubeIDE`
- `arm-none-eabi-gcc`
- `SolidWorks`
- ROS 1 环境（用于已有 URDF/launch 资源的显示与验证）

仓库中可直接看到：

- `robot.ioc`
- `STM32H723VGTX_FLASH_USER.ld`
- `robot.code-workspace`

---

## 14. 编译与使用建议

### 14.1. 固件

1. 使用 `STM32CubeMX` / `STM32CubeIDE` 打开 `chassis_control_code/robot.ioc`
2. 检查本地 STM32H7 固件包版本是否兼容
3. 生成或刷新工程
4. 编译并下载到 `STM32H723VGT6`
5. 按实际接线确认 CAN、IMU、遥控接收器、总线舵机、RGB 灯工作正常

### 14.2. 机械臂描述

如需单独查看机械臂描述资源，可优先从以下目录入手：

- `chassis_control_code/arm_description/`
- `model/URDF_arm/ARM/`

---

## 15. 已知特点与局限

- 原型属性明显，机械与控制参数仍可能频繁调整
- 当前 README 以仓库已有代码与模型为准，不等同于完整 BOM 或接线手册
- 机械臂上层任务规划、视觉闭环与 ROS 总体系统尚未完成集成
- 遥控逻辑更偏调试/验证用途，正式任务系统仍需要进一步抽象
- 舵机串口读回目前在 `assemble_arm.c` 中尚未真正实现接收逻辑，后续可继续完善闭环能力

---

## 16. 后续开发方向

- 完善机械臂抓取器与末端执行器设计
- 增加完整电气连接图、BOM 与调参手册
- 补充底盘/机械臂联合测试流程
- 将 URDF、运动学与实际控制参数做更系统的一致性校准
- 接入 ROS 视觉、导航、任务规划与仿真链路
- 把 `Atlas` 与后续平台抽象到可复用的共性框架中

---

## 17. 仓库关系

`SteerWheel Mk.1` 是本仓库的第一代验证平台；后续的 `Atlas` 与另一台尚未命名的轮式机器人，会在这个原型的基础上继续演化：

- 底盘：继续采用舵轮方案
- 机械臂：继续采用五轴五自由度方案
- 软件：逐步向更清晰的模块复用与 ROS 上层融合演进

如果你要从本仓库开始接手开发，建议先熟悉 `SteerWheel Mk.1`，再迁移理解到后续车型

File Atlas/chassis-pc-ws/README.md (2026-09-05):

# Atlas PC Teleop App

该目录是 PC 端主从臂遥操作 GUI，不是命令行遥操作脚本，也不属于树莓派 ROS2 自主任务栈

## 从源码运行

Windows PowerShell：

```powershell
cd Atlas\chassis-pc-ws
py -m pip install -r requirements.txt
py scripts\main.py
```

Linux：

```bash
cd Atlas/chassis-pc-ws
python3 -m pip install -r requirements.txt
python3 scripts/main.py
```

App 启动后点击“扫描串口”，选择或填写“主臂串口”和“从臂 MCU 串口”，应用配置后点击“开始运行”；两个设备不能选择同一个串口；串口被其他程序占用时应先释放

## Windows 打包

先安装打包工具，再从 `scripts` 目录构建：

```powershell
cd Atlas\chassis-pc-ws
py -m pip install -r requirements.txt
py -m pip install pyinstaller
cd scripts
py -m PyInstaller `
    --noconfirm `
    --clean `
    --name AtlasTeleop `
    --windowed `
    --onedir `
    --icon ".\assets\app.ico" `
    --add-data ".\qml:qml" `
    --add-data ".\assets:assets" `
    ".\main.py"
```

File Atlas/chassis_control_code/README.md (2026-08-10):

# chassis_control_code

`chassis_control_code` 是 Atlas 的 STM32 MCU 实时控制代码；它负责底盘、机械臂、IMU/里程计、遥控器、PC/Pi 通信以及本地安全状态机，不负责导航、视觉和整车任务规划

## 1. 目录结构

```text
chassis_control_code/
├── robot.ioc                    # CubeMX 配置
├── arm_description/             # URDF、关节配置、MATLAB 模型
└── src/
    ├── platform/                # STM32 HAL 适配
    ├── device/                  # 电机、舵机、IMU、遥控器、RGB
    ├── domain/                  # 运动学、Kalman、纯数学模型
    ├── infra/                   # 二进制帧、解析器、HFSM、PID、日志、矩阵、时间
    ├── service/                 # chassis/odom/arm/remote/pc_comms/pi_comms/asr_comms
    │   └── assemble/            # 设备与平台装配
    └── app/                     # entry、runtime、FSM、control、status
```

依赖方向建议保持：

```text
app -> service -> domain/device -> infra/platform
```

`domain` 和 `infra` 不应直接依赖 STM32 HAL

## 2. 启动与调度

应用入口位于 `src/app/entry.h``entry_init()` 的装配顺序为：

```text
delay -> log -> rgb -> imu -> odom -> chassis -> arm -> remote
      -> pc_comms -> pi_comms -> asr_comms -> app_runtime/app_status -> TIM6 500Hz
```

`entry_loop()` 调度：

| 频率 | 任务 |
|---:|---|
| 500 Hz | `chassis.process()`、`app_runtime_process()` |
| 250 Hz | `odom.process()` |
| 100 Hz | `remote_process()`、`pc_comms_process()`、`pi_comms_process()`、`asr_comms_process()` |
| 50 Hz | `arm.refresh_current_state()` |
| 后台 | LED、Pi 状态/传感器发送、1 Hz 日志 |

Pi 发送采用 2 ms 槽位错峰：IMU 100 Hz、ODOM 50 Hz、ARM_STATE 50 Hz、STATUS 10 Hz

## 3. 本地状态机

状态定义：

| 值 | 状态 | 说明 |
|---:|---|---|
| 0 | Idle | 安全停止，等待人工输入 |
| 1 | Manual | 遥控手动控制 |
| 2 | AutoPi | 接受 Pi 自动控制 |
| 3 | Fault | 锁存故障，只有 recoverable 可清理 |
| 4 | EStop | 急停锁死，普通清理不能恢复 |
| 5 | Finished | Pi 上报任务完成后的停止态 |

手动子模式：

- `ManualChassisPcArm`：遥控底盘 + PC 主臂跟随
- `ManualArmFs`：遥控机械臂

注意：HFSM 的原始转移表仍允许 `Manual/Finished -> AutoPi`，但 `app_runtime` 只在 Idle 接受已武装的 ASR 自动启动事件；后续建议收紧底层转移表，形成双重约束

## 4. 遥控器模式与自动任务锁存

遥控器所有模式、手势和摇杆行为都由以下通道组合决定：

| 通道 | 作用 |
|---|---|
| `SWA` | 手动子模式选择 |
| `SWB` | 速度档位 |
| `SWC` | 手动底盘/机械臂局部行为，以及清理/复位手势的一部分 |
| `SWD` | 手动请求 / 自动启动请求 |
| `RIGHT_X` | 底盘横向、机械臂末端 yaw |
| `RIGHT_Y` | 底盘前后、机械臂末端 pitch / 伸缩 |
| `LEFT_X` | 底盘偏航、机械臂基座 yaw |
| `VRA` | 自动启动 / 清理复位门槛 |
| `VRB` | 自动启动 / 清理复位门槛 |

通道名对应关系见 `src/service/remote.h` 中的 `REMOTE_CH_*` 定义

### 4.1 `SWD`：手动请求与自动请求

`SWD` 是主模式开关：

| 条件 | 结果 |
|---|---|
| `SWD == REMOTE_SW_LOW` | 进入手动请求 |
| `SWD == REMOTE_SW_HIGH` 且 `VRA >= REMOTE_AUTO_THRESHOLD` 且 `VRB >= REMOTE_AUTO_THRESHOLD` | 自动启动条件成立 |
| 其他情况 | 不触发手动请求，也不触发自动启动 |

说明：

- `remote.c` 会把持续条件转换为一次性边沿事件
- 上电或遥控重连后，必须先离开对应条件，再重新进入，才会重新武装下一次事件
- `app_runtime` 只在 `Idle` 接受自动语音门控请求
- `SWD` 处于手动请求时，自动启动不生效
- 退出手动请求后，如果当前在 Manual，系统会停止底盘/机械臂并返回 Idle

### 4.2 `SWA`：手动子模式

`SWA` 只在手动请求生效时决定进入哪种手动子模式：

| 条件 | 结果 |
|---|---|
| `SWA == REMOTE_SW_HIGH` | `ManualChassisPcArm`：遥控底盘 + PC 主臂跟随 |
| `SWA == REMOTE_SW_LOW` | `ManualArmFs`：遥控机械臂 |
| `SWA == REMOTE_SW_CENTER` | 默认进入 `ManualChassisPcArm` |

说明：

- `remote.c` 里只有高/低两档会被显式识别为手动源，`app_runtime` 会把中位默认当作 `ManualChassisPcArm`
- `SWA` 本身不触发模式切换，只决定手动请求被接受后进入哪种 Manual 子模式

### 4.3 `SWB`：速度档位

`SWB` 不是模式开关，而是速度档位开关，手动底盘和手动机械臂都会受它影响

| 条件 | 底盘速度限制 | 机械臂速度限制 |
|---|---|---|
| `SWB == REMOTE_SW_LOW` | 快档：`2.0 / 2.0 / 8.0` | 快档：`50.24 / 1.5 / 3.0 / 21 / 21 / 50.24` |
| `SWB == REMOTE_SW_HIGH` | 慢档：`0.5 / 0.5 / 2.0` | 慢档：`12.56 / 0.5 / 1.0 / 7 / 7 / 12.56` |
| `SWB` 中位 | 中档：`1.0 / 1.0 / 4.0` | 中档：`25.12 / 1.0 / 2.0 / 14 / 14 / 25.12` |

注：上表数值顺序分别表示底盘的 `vx / vy / wz` 上限，以及机械臂的 `base_end_yaw / reach / z / end_pitch / end_yaw / servo` 速度上限

### 4.4 `SWC`：局部行为与清理/复位

`SWC` 在手动控制里决定底盘是否启用 steer-then-drive，也参与清理/复位手势：

| 条件 | 结果 |
|---|---|
| `SWC == REMOTE_SW_LOW` | 手动底盘关闭 steer-then-drive；手动机械臂按关节模式微调 `q3/q4` |
| `SWC == REMOTE_SW_CENTER` | 手动底盘开启 steer-then-drive；手动机械臂按基座 yaw + 末端位姿模式控制 |
| `SWC == REMOTE_SW_HIGH` | 手动底盘直接刹停；手动机械臂仅在从非高位切入时执行一次 `move_servo_zero()`，并清空吸盘；同时作为清理/复位手势的一部分 |

### 4.4.1 手动底盘摇杆映射

仅在 `ManualChassisPcArm` 且遥控在线时生效

| 输入 | 作用 |
|---|---|
| `RIGHT_Y` | 底盘前后速度 `vx` |
| `RIGHT_X` | 底盘横向速度 `vy` |
| `LEFT_X` | 底盘角速度 `wz` |
| `SWB` | 速度上限档位 |

附加规则：

- `SWC == REMOTE_SW_LOW` 时，steer-then-drive 关闭
- `SWC == REMOTE_SW_CENTER` 时，steer-then-drive 开启
- `SWC == REMOTE_SW_HIGH` 或 `VRA <= REMOTE_VR_LOW_THRESHOLD` 时，底盘直接刹停
- `VRB > REMOTE_VR_LOW_THRESHOLD` 时，底盘不再输出速度，而是把目标置零并重置 yaw hold
- 只有在 `VRA` 和 `VRB` 都满足低位控制窗口时，才会真正把摇杆映射成连续速度控制

### 4.4.2 手动机械臂摇杆映射

仅在 `ManualArmFs` 或 `ManualChassisPcArm` 且遥控在线时生效

| 输入 | `SWC == REMOTE_SW_LOW` 时作用 | `SWC == REMOTE_SW_CENTER` 时作用 |
|---|---|---|
| `LEFT_X` | 不参与机械臂控制 | 基座 yaw 微调 |
| `RIGHT_Y` | 末端 pitch / 关节 3 控制 | 末端沿当前基座方向前后移动 |
| `RIGHT_X` | 末端 yaw / 关节 4 控制 | 末端高度控制 |

附加规则：

- `SWC == REMOTE_SW_HIGH` 时，机械臂只做一次 `move_servo_zero()`，之后保持静止
- `VRB > REMOTE_VR_LOW_THRESHOLD` 时，机械臂不接收连续摇杆控制
- 每次手动机械臂动作都会强制关闭吸盘，即 `suction_set(false)`

清理/复位条件为遥控器持续满足以下组合：

```text
SWC == REMOTE_SW_HIGH
VRA <= REMOTE_VR_LOW_THRESHOLD
VRB <= REMOTE_VR_LOW_THRESHOLD
```

边沿触发后：

- `auto_start_latched = 0`
- 清除 pending 自动启动事件
- 清除 `voice_gate_armed` 和 pending ASR `AUTO_START` 事件
- 清除 PC 主臂缓存、Pi 普通控制/动作、yaw hold
- 停止底盘和机械臂
- AutoPi/Finished 转 Idle
- recoverable Fault 清除后转 Idle
- Manual 保持 Manual
- EStop 保持 EStop

任务 DONE/FAIL 或遥控器退出自动位置都不会自动解锁，必须执行一次清理/复位手势

### 4.5 自动启动手势

自动启动条件为遥控器持续满足以下组合：

```text
SWD == REMOTE_SW_HIGH
VRA >= REMOTE_AUTO_THRESHOLD
VRB >= REMOTE_AUTO_THRESHOLD
```

遥控自动手势只请求 MCU 开启一次 ASRPro 语音门控，不直接设置 `auto_start_latched`，也不直接执行 `Idle -> AutoPi`

MCU 仅在以下条件全部满足时发送 `SPK,1\n` 并设置本地 `voice_gate_armed`：

- 当前为 Idle
- `auto_start_latched == 0`
- 无锁存 Fault、非 EStop
- Pi online
- chassis ready
- odom ready

完整流程：

```text
遥控自动手势
        ↓
MCU 检查基本启动条件并发送 SPK,1
        ↓
ASRPro 依次播报门控提示
        ↓
用户说“阿特拉斯启动”
        ↓
ASRPro 返回 EVT,AUTO_START
        ↓
MCU 检查 voice_gate_armed，并重新完整检查安全条件
        ↓
auto_start_latched = 1
Idle -> AutoPi
        ↓
MCU best-effort 发送 SPK,2
        ↓
ASRPro 播报“开始执行全自主运输任务”
```

ASRPro 识别成功后只返回 `EVT,AUTO_START`，不会自行宣布任务开始。只有 MCU 完成安全复核并实际进入 `AutoPi` 后才发送 `SPK,2`；发送失败只记录日志，不回滚任务状态

如果发送 `SPK,1` 后 Pi 掉线、chassis/odom 失去 ready、进入 Fault/EStop 或切回 Manual，晚到的 `EVT,AUTO_START` 不会获得自动启动许可，也不会触发 `SPK,2`

### 4.6 触发语义总述

`remote.c` 不会把“拨到位”直接当作命令，而是把持续条件变成一次性事件：

- 自动启动需要 `SWD` 高位 + `VRA/VRB` 高位，并且先离开再重新进入才会再次触发
- 清理/复位需要 `SWC` 高位 + `VRA/VRB` 低位，并且先离开再重新进入才会再次触发
- 手动请求由 `SWD` 低位触发，进入后由 `SWA` 决定手动子模式
- `SWB` 始终只影响速度档，不改变状态机模式
- `SWC` 高位在手动机械臂中还会触发一次性的零位收拢动作

## 5. 控制权限

| 数据/动作 | 生效状态 |
|---|---|
| `PC_MASTER_JOINTS` | Manual + `ManualChassisPcArm` |
| 遥控底盘 | Manual |
| 遥控机械臂 | Manual + `ManualArmFs` |
| `PI_CONTROL` 底盘 | AutoPi |
| `PI_CONTROL` 机械臂 | AutoPi，`command_seq` 单次消费 |
| `PI_YAW_ACTION` | 合适的 AutoPi 控制周期 |
| `PI_MISSION_EVENT` | 仅 AutoPi |
| `PI_ESTOP` | 任意状态 |

通信 service 只负责解析和缓存，权限判断位于 `app_runtime/app_control`

## 6. 状态和日志

`MCU_STATUS` 16 字节中 offset 12 为 `auto_start_latched`；1 Hz Heartbeat 日志示例：

```text
Heartbeat state=AutoPi manual=ManualChassisPcArm remote=1 pc=1 pi=1 auto_start=1 fault=0 src=0 level=0 code=0
```

RGB 状态：

| 状态 | 颜色 |
|---|---|
| 未 ready | 红 |
| Idle/Finished ready | 绿 |
| Manual | 蓝 |
| AutoPi | 青 |
| Fault | 橙 |
| EStop | 紫 |

## 7. 关键接口

- `src/app/app_runtime.*`：模式仲裁、安全和自动任务锁存
- `src/app/app_fsm.*`：本地 HFSM
- `src/app/app_control.*`：遥控/Pi 命令到执行机构的映射
- `src/app/app_status.*`：状态、传感器发送和日志
- `src/service/pi_comms.*`：Pi 帧解析、控制缓存和 MCU 上行帧
- `src/service/pc_comms.*`：PC 主臂帧
- `src/service/asr_comms.*`：ASRPro `SPK` 编码、`EVT,AUTO_START` 解析和 pending 事件
- `src/service/remote.*`：遥控状态与边沿事件
- `src/infra/binary_frame.*`：统一线协议

PC/Pi 主协议见 [`../docs/comms_protocol.md`](../docs/comms_protocol.md)，ASRPro ↔ MCU 协议见 [`../docs/asrpro_mcu_protocol.md`](../docs/asrpro_mcu_protocol.md)

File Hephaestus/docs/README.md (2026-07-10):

# Atlas 文档入口

Pi 端全自主运输文档统一维护在

```text
../chassis-pi-ws/docs/
```

包含

```text
配置指南.md
使用说明与教程.md
工作区详细介绍及完整任务流.md
状态机详细说明及错误处理.md
ASRPRO_TWEN51适配与烧录说明.md
串口固定绑定教程.md
视觉模型配置与标定.md
comms_protocol.md
```

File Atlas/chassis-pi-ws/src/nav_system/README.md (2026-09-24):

# Atlas：持续激光校正 + Odom 直达

正式比赛默认使用 `atlas_nav_direct_backend`。进入全自主后，机械臂/视觉先完成智能分拣观察并判定 `arena=A/B`；随后第一次 `origin` 导航只加载该 arena 对应的已标定地图与 pbstream，启动 Cartographer 纯定位完成地图匹配。定位稳定后保持 Cartographer 运行，对 `map -> odom` 做限速、防跳变的持续校正。后续 `pickup / park_1 / park_2` 依然由轻量 `/odom` 直达控制器闭环，不让 Navfn、DWB、costmap 或 BT Navigator 参与控制。

速度输出仍为 `/atlas/navigation/cmd_vel`，由 YASMIN 安全门控后转发到 `/motor_cmd_vel`。原 `atlas_nav_full_backend + at_nav2` 完整 Nav2 链路仍保留在仓库中作为备用和调试方案。

---

---

## Atlas 任务系统集成说明

当前导航目录保留三类后端：

| 后端 | 包 | 用途 |
| --- | --- | --- |
| `direct` | `atlas_nav_direct_backend` + `at_nav2` 启动定位 | **正式比赛默认**；激光持续校正，`/odom` 轻量直达。 |
| `full` | `atlas_nav_full_backend` + `at_nav2` | 备用；通过 Nav2 `NavigateToPose` 执行完整导航。 |
| `pseudo` | `atlas_nav_pseudo_backend` | 仅联调；不依赖地图，用 `/odom` 做相对位移。 |

正式比赛统一入口：

```bash
ros2 launch atlas_competition_bringup competition_stack.launch.py
```

其中 direct 后端输出 `/atlas/navigation/cmd_vel`；最终到底层 MCU 的 `/motor_cmd_vel` 仍由 `atlas_mission_yasmin` 根据 AutoPi、任务阶段、Fault/EStop/Manual 等条件门控后发布。完整 Nav2 后端保留用于备用调试，不参与默认比赛链路。

# navigation_system — AGT 比赛轮式机器人导航系统

> **ROS2 Humble 比赛导航系统**：正式比赛采用 Cartographer 持续校正 + odom 直达；同时保留完整 Nav2 链路用于备用调试。

本系统面向 AGT 比赛场景，采用 **ROS2 Humble** 作为中间件框架，**Cartographer 2D 纯定位** 提供全局位姿估计，**Nav2（Navfn + DWB）** 负责全局规划与局部运动控制，**LSLIDAR N10P** 单线激光雷达为感知输入。

---

## 1. 系统架构

```mermaid
graph TD
    subgraph 启动层
        startup[robot_startup<br/>总启动入口]
    end

    subgraph 感知层
        msgs[lslidar_msgs<br/>消息/服务接口定义] -.->|rosidl 编译依赖| driver
        driver[lslidar_driver<br/>N10P UART 驱动] -->|sensor_msgs/LaserScan| scan["/scan"]
    end

    subgraph 模型层
        desc[robot_description<br/>URDF 模型 + TF]
        desc -->|robot_state_publisher<br/>/tf_static| tf_tree[TF 变换树]
    end

    subgraph 建图层
        mapping[robot_cartographer_mapping<br/>Cartographer 2D SLAM] -->|/map| map_topic
        mapping -->|生成| pbstream[pbstream 文件]
        mapping -->|导出| pgm_yaml[PGM + YAML 地图]
    end

    subgraph 导航层
        nav2[at_nav2<br/>Nav2 导航栈] -->|Cartographer 纯定位| loc[全局位姿估计]
        nav2 -->|Navfn 全局规划| gp[全局路径]
        nav2 -->|DWB 局部控制| lc[局部速度指令]
        nav2 -->|geometry_msgs/Twist| cmd_vel["/cmd_vel"]
        pbstream -.->|纯定位初始状态| loc
        pgm_yaml -.->|全局代价地图| nav2
    end

    subgraph 控制层
        mcu[mcu_comm_bridge<br/>MCU 通信桥接]
        mission[atlas_mission_manager<br/>任务状态机]
        cmd_vel -->|remap| nav_gate["/atlas/navigation/cmd_vel"]
        nav_gate -->|安全门控| mission
        mission -->|geometry_msgs/Twist| motor_cmd_vel["/motor_cmd_vel"]
        motor_cmd_vel -->|速度指令| mcu
        motor_cmd_vel -->|串口| chassis[全向轮式底盘]
        mission -->|StartNavigation| full_backend[atlas_nav_full_backend]
        full_backend -->|NavigateToPose Action| nav2
    end

    startup -->|IncludeLaunch| driver
    startup -->|IncludeLaunch| desc
    startup -->|IncludeLaunch| nav2
    startup -->|IncludeLaunch| mcu
    startup -->|IncludeLaunch| mission

    scan --> mapping
    scan --> nav2
```

> 虚线表示编译时依赖或非实时数据流，实线表示运行时话题/服务通信。

---

## 2. 功能包清单

本 monorepo 包含 7 个功能包，按系统层次排列：

| 包名 | 定位 | 核心依赖 | 类型 |
|---|---|---|---|
| [`lslidar_msgs`](./lslidar_msgs/) | 雷达消息与服务接口定义 | `builtin_interfaces`, `rosidl_default_generators` | 纯接口包 |
| [`lslidar_driver`](./lslidar_driver/) | LSLIDAR N10P UART 驱动节点 | `lslidar_msgs`, `rclcpp`, `sensor_msgs`, `pcl_conversions`, `libpcap` | 驱动包 |
| [`robot_description`](./robot_description/) | URDF 模型 + robot_state_publisher | `robot_state_publisher`, `rviz2` | 模型包 |
| [`robot_cartographer_mapping`](./robot_cartographer_mapping/) | Cartographer 2D SLAM 建图 | `cartographer_ros`, `nav2_map_server` | 建图包 |
| [`at_nav2`](./at_nav2/) | Nav2 导航栈 + Cartographer 纯定位 | `nav2_bringup`, `nav2_planner`, `nav2_controller`, `cartographer_ros` | 导航包 |
| [`atlas_nav_full_backend`](./atlas_nav_full_backend/) | 任务完整导航后端，包装 Nav2 `NavigateToPose` | `rclpy`, `nav2_msgs`, `atlas_mission_interfaces` | 适配包 |
| [`atlas_nav_pseudo_backend`](./atlas_nav_pseudo_backend/) | 伪导航后端，用于安全联调 | `rclpy`, `atlas_mission_interfaces` | 适配包 |
| [`robot_startup`](./robot_startup/) | PI 端总启动入口 | `mcu_comm_bridge`, `lslidar_driver`, `robot_description`, `atlas_mission_manager` | 启动包 |

> `mcu_comm_bridge` 为底盘驱动桥接外部依赖包，不在本目录中。

---

## 3. 快速开始

### 3.1 环境准备

在 Ubuntu 22.04 上安装必需的系统依赖和 ROS2 包：

```bash
# 系统依赖
sudo apt install -y build-essential cmake git python3-colcon-common-extensions \
  python3-rosdep libpcl-dev libpcap-dev libyaml-cpp-dev libboost-all-dev

# ROS2 Humble 核心包
sudo apt install -y ros-humble-desktop ros-humble-rosidl-default-generators

# 导航栈
sudo apt install -y ros-humble-navigation2 ros-humble-nav2-bringup \
  ros-humble-nav2-map-server ros-humble-nav2-planner ros-humble-nav2-controller

# Cartographer
sudo apt install -y ros-humble-cartographer ros-humble-cartographer-ros

# TF 与可视化
sudo apt install -y ros-humble-robot-state-publisher ros-humble-rviz2

# 依赖初始化
sudo rosdep init && rosdep update
```

### 3.2 克隆与构建

```bash
# 创建工作空间
mkdir -p ~/chassis-pi-ws/src
cd ~/chassis-pi-ws

# 克隆本仓库
# 如果已经位于 Atlas/chassis-pi-ws，可直接跳过 clone
# git clone <repo-url> src/Atlas

# 安装所有依赖
rosdep install --from-paths src --ignore-src -r -y

# 构建全部包
colcon build --symlink-install
source install/setup.bash
```

### 3.3 真机建图

启动 Cartographer 建图（含雷达、MCU 桥接、TF）：

```bash
source ~/chassis-pi-ws/install/setup.bash
ros2 launch robot_cartographer_mapping robot_cartographer_mapping.launch.py
```

用键盘/手柄遥控机器人在场地中移动，覆盖目标区域后保存地图：

```bash
# 保存 pbstream（用于后续纯定位）
ros2 service call /write_state cartographer_ros_msgs/srv/WriteState \
  "{filename: '$(pwd)/my_map.pbstream'}"

# 导出 PGM + YAML（用于 Nav2 全局代价地图）
ros2 run nav2_map_server map_saver_cli -t map -f my_map
```

### 3.4 真机导航

将建图产物（`my_map.pbstream`、`my_map.pgm`、`my_map.yaml`）放入 `at_nav2/maps/` 目录，并在 `at_nav.launch.py` 中指定这些文件后，一键启动：

```bash
source ~/chassis-pi-ws/install/setup.bash
ros2 launch robot_startup robot_start.launch.py
```

该 launch 文件会拉起：
1. `mcu_comm_bridge` — MCU 通信桥接，提供 `/odom`、`/imu`、机械臂状态和 `/motor_cmd_vel` 输入
2. `lslidar_driver` — N10P 雷达驱动，提供 `/scan`
3. `robot_description` — URDF + TF 发布
4. `atlas_mission_manager` — 任务状态机、完整导航后端和 RACOM 视觉作业链路
5. `at_nav2` — 由 `mission_stack.launch.py` 在 `navigation_backend:=full` 时启动

---

## 4. 核心数据流

| Topic | 发布者 | 订阅者 | 说明 |
|---|---|---|---|
| `/scan` | `lslidar_driver` | `cartographer_node`, `nav2_costmap_2d` | N10P 单线激光扫描数据（sensor_msgs/LaserScan） |
| `/odom` | 底盘里程计 / MCU 桥接 | `cartographer_node`, `nav2_controller` | 轮式里程计，提供局部运动估计（nav_msgs/Odometry） |
| `/map` | `cartographer_node` | `nav2_costmap_2d`（global costmap） | SLAM 生成的占据栅格地图（nav_msgs/OccupancyGrid） |
| `/atlas/navigation/cmd_vel` | `nav2_controller` 经 remap | `atlas_mission_manager` | Nav2 输出的导航速度，先进入任务安全门控 |
| `/motor_cmd_vel` | `atlas_mission_manager` | `mcu_comm_bridge` | 门控后的底盘实际速度指令 |
| `/joint_states` | 底盘编码器 / MCU 桥接 | `robot_state_publisher` | 各关节状态（sensor_msgs/JointState），驱动 TF 动态发布 |
| `map -> odom` TF | `cartographer_node` | `robot_state_publisher` / `nav2_controller` | 全局定位修正变换 |
| `odom -> base_footprint` TF | 里程计节点 | `robot_state_publisher` / `nav2_costmap_2d` | 局部运动估计变换 |
| `base_link -> laser_link` TF | `robot_state_publisher`（URDF static） | `cartographer_node`, `nav2_costmap_2d` | LiDAR 传感器安装位姿（fixed joint） |

> TF 完整链路：`map -> odom -> base_footprint -> base_link -> laser_link`（及各轮段）

---

## 5. 硬件/软件要求

| 类别 | 项目 | 要求 |
|---|---|---|
| **操作系统** | Ubuntu | 22.04 LTS（Jammy） |
| **ROS2** | Humble Hawksbill | 桌面完整版（desktop） |
| **编译器** | GCC / Clang | C++17 标准 |
| **脚本语言** | Python | 3.10+（含 typing） |
| **雷达** | LSLIDAR N10P | 单线激光雷达，UART 串口通信 |
| **底盘** | 全向轮式底盘 | 四轮独立转向 + 独立驱动 |
| **MCU** | MCU 通信桥接 | `mcu_comm_bridge` 包（串口 / CAN） |
| **构建系统** | colcon | 需 `--symlink-install` 支持 |

---

## 6. 完整目录树

```
navigation_system/
├── README.md                                 # 本文档（总入口）
│
├── lslidar_msgs/                             # 雷达消息/服务接口包
│   ├── msg/                                  #   自定义消息（LslidarInformation, LslidarPacket）
│   ├── srv/                                  #   自定义服务（IpAndPort, MotorControl, TimeMode 等 11 项）
│   ├── CMakeLists.txt
│   ├── package.xml
│   └── README.md
│
├── lslidar_driver/                           # 雷达驱动包（N10P UART）
│   ├── config/                               #   雷达参数 YAML 配置
│   ├── include/lslidar_driver/               #   头文件（点云类型定义、驱动核心）
│   ├── launch/                               #   启动文件
│   ├── src/                                  #   驱动源码
│   ├── CMakeLists.txt
│   ├── package.xml
│   └── README.md
│
├── robot_description/                        # URDF 模型与 TF
│   ├── urdf/                                 #   robot_description.urdf
│   ├── meshes/                               #   STL 网格（底盘、车轮、LiDAR 支架）
│   ├── launch/                               #   robot_description.launch.py
│   ├── CMakeLists.txt
│   ├── package.xml
│   └── README.md
│
├── robot_cartographer_mapping/               # Cartographer 2D SLAM 建图
│   ├── config/                               #   robot_2d.lua（SLAM 参数）
│   ├── launch/                               #   robot_cartographer_mapping.launch.py
│   ├── CMakeLists.txt
│   ├── package.xml
│   └── README.md
│
├── at_nav2/                                  # Nav2 导航栈 + Cartographer 纯定位
│   ├── config/                               #   Nav2 参数 + BT XML + Cartographer 定位 LUA
│   ├── launch/                               #   at_nav.launch.py
│   ├── maps/                                 #   导航用地图（ruikang.pbstream/pgm/yaml）
│   ├── rviz2/                                #   RViz2 可视化配置（预留）
│   ├── CMakeLists.txt
│   ├── package.xml
│   └── README.md
│
├── robot_startup/                            # 总启动入口
│   ├── launch/                               #   robot_start.launch.py
│   ├── CMakeLists.txt
│   ├── package.xml
│   └── README.md
│
├── atlas_nav_full_backend/                   # 完整导航后端适配器
│   ├── config/full_nav.yaml
│   ├── launch/full_nav_backend.launch.py
│   └── README.md
│
├── atlas_nav_pseudo_backend/                 # 伪导航后端
│   ├── config/pseudo_nav.yaml
│   ├── launch/pseudo_nav.launch.py
│   └── README.md
│
└── robot_startup/                            # PI 端总启动入口
    ├── launch/robot_start.launch.py
    ├── CMakeLists.txt
    ├── package.xml
    └── README.md
```

---

## 7. 维护者

**AGT Dev Team** — 竞赛机器人导航系统开发与维护。

如有问题或建议，请提交 Issue 或通过仓库联系。

---

## 8. 相关链接

| 资源 | 链接 |
|---|---|
| Navigation2 文档 | https://docs.nav2.org |
| Nav2 GitHub | https://github.com/ros-navigation/navigation2 |
| Cartographer ROS 文档 | https://google-cartographer-ros.readthedocs.io |
| Cartographer GitHub | https://github.com/cartographer-project/cartographer_ros |
| LSLIDAR 官方 | https://www.lslidar.com |
| ROS2 Humble 文档 | https://docs.ros.org/en/humble |
| ROS2 TF2 教程 | https://docs.ros.org/en/humble/Tutorials/Intermediate/Tf2 |

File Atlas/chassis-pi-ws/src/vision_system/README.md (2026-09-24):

# screw_pick — 螺丝视觉抓取系统

基于 ROS 2 的视觉抓取工程，包含相机标定、手眼标定、YOLO 目标检测、像素到机械臂基座坐标变换，以及抓取目标选择。

## 1. 项目组成

```text
screw_pick/
├── calib/                    # 相机内参和手眼标定脚本
├── handeye_bridge/           # 坐标变换、深度计算、机械臂控制
├── vison_topic/              # YOLO ONNX 检测节点
├── vison_topic_interfaces/   # 自定义 msg / srv
└── README.md
```

主要数据流：

```text
相机图像
  → vison_topic 检测目标中心
  → /detection_centers
  → handeye_bridge 匹配检测时间与机械臂位姿
  → 像素/深度转换为 base 坐标
  → /pick_target 选择目标和层
  → /mcu/set_arm_pose
```

## 2. 使用前必须确认

在允许机械臂自动运动前，依次确认：

1. 相机分辨率与内参标定一致，当前工程要求 `640×480`。
2. 更换相机、焦距、分辨率或内参后，重新采集手眼样本并求解。
3. `handeye_bridge/config/bridge_node.yaml` 中的初始观察位已经空载验证。
4. 三层工作高度或 PnP 目标尺寸已经实测。
5. 新标定文件已经复制到 `handeye_bridge/config/` 并重新构建。
6. 首次验证时保持 `auto_send: false`，只观察计算坐标。

> 当前配置文件中的 `initial_pose_configured`、`plane_heights_configured` 和
> `auto_send` 可能已经是 `true`。换设备或重新部署时，不要直接沿用；应先改为
> `false`，完成空载验证后再逐项开启。

## 3. 环境与构建

以下目录约定：

- 项目源码根目录：包含 `calib/`、`handeye_bridge/`、`vison_topic/`。
- ROS 2 工作空间根目录：包含 `src/`、`build/`、`install/`、`log/`。

若本项目位于 ROS 2 工作空间的 `src/screw_pick/`：

```bash
cd ~/ros2_ws
colcon build --packages-select \
    vison_topic_interfaces vison_topic handeye_bridge
source install/setup.bash
```

修改下列内容后必须重新构建并重新 `source`：

- `.msg` 或 `.srv` 接口；
- Python 节点代码；
- launch 文件；
- `handeye_bridge/config/` 中打包安装的 YAML。

## 4. 标定流程

所有标定命令都从项目源码根目录执行。

### 4.1 相机内参标定

先确认 `calib/camera_calib.py` 中的棋盘格内角点数量和方格尺寸与实物一致：

```bash
python calib/camera_calib.py
```

建议采集 20～30 张：棋盘覆盖画面中心、四角和边缘，并包含不同距离与倾角。不要只在画面中心平移棋盘。

输出文件：

```text
calib/camera_intrinsics.yaml
```

内参标定完成后应检查 RMS 和单张重投影误差。畸变系数数值大不一定代表错误，但如果 RMS 很大、边缘直线校正后仍明显弯曲，通常需要检查：

- 棋盘格行列数是否填写反了；
- 方格尺寸和单位是否正确；
- 图片是否模糊、反光或棋盘不平；
- 标定图片是否缺少边缘和倾斜姿态；
- 标定与运行分辨率是否都是 `640×480`；
- 自动对焦是否在采集过程中变化。

### 4.2 采集手眼样本

棋盘格必须固定不动，机械臂带着相机改变姿态：

```bash
# 正常模式，推荐
python calib/collect_samples.py

# 跳过质量门禁，仅用于诊断
python calib/collect_samples.py --minimal
```

建议采集 20～30 组，优先增加绕两个不同轴的旋转变化，避免大量重复或只有平移的姿态。

程序会拒绝近重复姿态，并拦截相邻样本间超过 120° 的棋盘格翻转。出现翻转提示时，不要手改 YAML；保持棋盘固定，换一个幅度较小的机械臂姿态重新采集。

### 4.3 诊断、求解与验证

```bash
# 求解前检查样本分布
python calib/diagnose.py calib/samples.yaml

# 常规求解：RANSAC + 全量相对运动 + LM 精化
python calib/solve.py calib/samples.yaml

# 可选：Bundle Adjustment
python calib/solve.py calib/samples.yaml --ba

# 使用已有结果验证
python calib/verify.py calib/samples.yaml \
    --result calib/samples_result.yaml
```

输出文件：

```text
calib/samples.yaml
calib/samples_result.yaml
```

求解至少需要 6 组有效样本，建议 20～30 组。不要只看“求解成功”，还要检查平移 RMS、旋转误差、内点数量和实际抓取验证结果。

## 5. 部署标定结果

先把标定结果从当前电脑同步到机器人。以下内容保留为项目的标准操作方式。

```bash
# rsync — 增量同步 (推荐)
rsync -avz calib/samples_result.yaml \
    wheeltec@192.168.0.100:screw_pick/calib/

# 或者用 scp — 单文件拷贝
scp calib/samples_result.yaml \
    wheeltec@192.168.0.100:screw_pick/calib/
```

相机内参有变化时也要同步：

```bash
rsync -avz calib/camera_intrinsics.yaml \
    wheeltec@192.168.0.100:screw_pick/calib/
```

部署前还需把结果复制到 `handeye_bridge/config/` 并重新构建；运行时读取安装空间中的相对配置路径。

```bash
cp calib/camera_intrinsics.yaml handeye_bridge/config/
cp calib/samples_result.yaml handeye_bridge/config/

cd ~/ros2_ws
colcon build --packages-select \
    vison_topic_interfaces vison_topic handeye_bridge
source install/setup.bash
```

## 6. SSH 显示转发 (X11 Forwarding)

脚本使用 OpenCV `imshow` 显示画面，SSH 到机器人时默认没有显示器。两种解决办法：

### 方案 A: SSH X11 转发（不改代码，推荐）

PC 上：

```bash
# Linux: X11 自带
# Windows: 先装 VcXsrv 并启动
# Mac: 先装 XQuartz 并启动

ssh -X wheeltec@192.168.0.100
```

机器人端确认 X11 转发已开启：

```bash
grep X11Forwarding /etc/ssh/sshd_config   # 应该是 yes
# 如果不是: sudo sed -i 's/.*X11Forwarding.*/X11Forwarding yes/' /etc/ssh/sshd_config
# sudo systemctl restart sshd
sudo apt install xauth  # 如果提示 xauth not found
```

### 方案 B: Headless 无头模式

加 `--headless` 参数，不弹窗口，终端输出状态，截图保存在项目内的相对目录 `calib/debug/`：

```bash
python calib/camera_calib.py --headless
# 终端显示: ✓ 检测成功 / ✗ 未检测到 | 已拍:N张 | [回车拍照 / C计算 / Q退出]
# 截图: calib/debug/calib_camera_debug.jpg

python calib/collect_samples.py --headless
# 终端显示: 距离=XXXmm | XXpx/格(优/可/差) | 重投影=X.XXXpx | 静止✓ | [回车采集 / Q退出]
# 截图: calib/debug/calib_debug.jpg
```

需要把调试截图拉回 PC 时：

```bash
scp wheeltec@192.168.0.100:screw_pick/calib/debug/calib_debug.jpg .
```

## 7. 深度与坐标变换

比赛深度模式在 `competition.yaml` 的 `competition.handeye_bridge` 中选择；
货物区第一、第二层高度来自顶层比赛配置中各观察位的标定结果；第三层以及
非比赛模式的回退高度在 `handeye_bridge/config/bridge_node.yaml` 中配置。

### 7.1 manual：固定工作平面，默认

```yaml
depth_mode: "manual"
plane1_z_m: -0.03
plane2_z_m: 0.12
plane3_z_m: 0.19
target_z_offset_m: 0.03
```

计算过程：像素去畸变后形成相机射线，经手眼矩阵和机械臂 FK 转换到 base 坐标系，再与目标层的绝对 Z 平面求交。比赛货物区 layer 1/2 使用当前 A/B、slot 对应的 `layer_z_m`；layer 3 使用 `plane3_z_m`。第一/二层识别成功后，机械臂先到目标 XY 的第三层等待高度，实时 FK 确认到位后再下探到目标层。

`planeX_z_m` 是机械臂基座坐标系中的平面高度，不是相机到平面的距离。测量方式：

```bash
ros2 topic echo /arm/pose --once
```

让末端到达对应工作平面，读取位置中的 `z`，分别填入三层参数。最终发送高度为：

```text
目标 Z = planeX_z_m + target_z_offset_m + manual_offset_z_m
```

比赛配置加载时会根据每个货物观察位自动派生：

```text
camera_to_plane1_distance_m = observation.z_m - layer_z_m[0]
camera_to_plane2_distance_m = observation.z_m - layer_z_m[1]
```

这两个 TCP 高度差用于诊断和复核；manual 模式射线求交直接使用同一标定中的
绝对 `layer_z_m`，不需要人工维护第二份深度值。

### 7.2 pnp：四点矩形深度

```yaml
depth_mode: "pnp"
pnp_target_width_m: 0.05
pnp_target_height_m: 0.05
pnp_max_reprojection_px: 2.0
pnp_min_depth_m: 0.05
pnp_max_depth_m: 0.80
```

PnP 模式要求同时检测到四个角，并且四点确实对应一个已知尺寸的平面矩形。宽高必须填写四个目标中心之间的真实距离。缺点、排序错误或目标并非矩形时，PnP 深度不可靠。

## 8. 检测排序与目标编号

四目标编号约定：

```text
0 左上 ───────── 1 右上
  │                 │
  │                 │
3 左下 ───────── 2 右下
```

`corner_index` 的含义：

| 值 | 位置 |
|---:|---|
| 0 | 左上 TL |
| 1 | 右上 TR |
| 2 | 右下 BR |
| 3 | 左下 BL |

当前检测代码最多取置信度最高的 4 个目标参与分配。PnP 必须有完整四点；少于四点时不要把缺失角的身份当作已经可靠恢复。

## 9. 启动与操作

### 9.1 一键启动

```bash
# 默认无预览，适合机器人部署
ros2 launch handeye_bridge screw_pick.launch.py

# 显示 OpenCV 预览，需要本地桌面或 X11
ros2 launch handeye_bridge screw_pick.launch.py no_preview:=false
```

bridge 启动后会按照配置尝试回到初始观察位。确认到位门禁：

```bash
ros2 topic echo /initial_pose_ready --once
```

需要重新发送初始观察位时：

```bash
ros2 service call /move_to_initial_pose std_srvs/srv/Trigger "{}"
```

### 9.2 开始和停止检测

```bash
# 开始持续检测
ros2 service call /vision_detect \
    vison_topic_interfaces/srv/VisionDetect "{start: true}"

# 查看实时检测结果
ros2 topic echo /detection_centers

# 停止检测并返回本次检测的最佳结果
ros2 service call /vision_detect \
    vison_topic_interfaces/srv/VisionDetect "{start: false}"
```

停止时的最佳帧会以 `is_final_best: true` 再发布一次，并保留原始采集时间戳。bridge 使用该时间戳匹配采集当时的机械臂位姿。

### 9.3 选择目标与工作层

```bash
# 选择左上目标，第 1 层
ros2 topic pub /pick_target \
    vison_topic_interfaces/msg/PickTarget \
    "{corner_index: 0, layer: 1}" --once

# 选择右下目标，第 3 层
ros2 topic pub /pick_target \
    vison_topic_interfaces/msg/PickTarget \
    "{corner_index: 2, layer: 3}" --once
```

`auto_send: false` 时只计算并打印坐标；`auto_send: true` 才调用机械臂服务。建议按以下顺序验证：

1. `auto_send: false`，检查中心和边缘多个目标的坐标。
2. 检查三层高度、同步误差和 workspace 门禁。
3. 让机械臂在目标上方空载运动，确认方向和量级。
4. 最后再开启 `auto_send: true`。

## 10. ROS 接口

| 名称 | 类型 | 用途 |
|---|---|---|
| `/vision_detect` | `VisionDetect` 服务 | 启动或停止检测 |
| `/vision_detections` | `Float32MultiArray` | 原始实时检测数据 |
| `/detection_centers` | `DetectionCenterArray` | 带时间戳和角编号的中心点 |
| `/pick_target` | `PickTarget` | 选择目标编号和高度层 |
| `/arm/pose` | `PoseStamped` | MCU FK 末端位姿 |
| `/move_to_initial_pose` | `Trigger` 服务 | 返回初始观察位 |
| `/initial_pose_ready` | `Bool` | 初始观察位到位门禁 |
| `/mcu/set_arm_pose` | 机械臂服务 | 发送目标位姿 |

## 11. 常见问题

### 第二天使用相同深度，结果仍发生变化

优先检查相机支架、机械臂零位、相机焦距/自动对焦、工作平面是否移动，以及检测框中心是否漂移。手眼矩阵和内参都默认相机相对末端刚性不变；相机发生轻微转动，也会让画面边缘产生明显坐标误差。

### 一个目标准确，四个目标误差不同

这通常不是一个统一的常量偏置。重点检查内参和畸变、手眼旋转误差、检测点定义是否一致，以及平面是否真的与 base 的 XY 平面平行。只调 `manual_offset_x/y` 只能补偿整体偏差，不能修复随画面位置变化的误差。

### PnP 深度跳动

PnP 对四点中心误差、点顺序、物理宽高和矩形假设非常敏感。先看重投影误差；若四个目标不是刚性固定的矩形，不应使用 PnP 推算共同深度。

### 无法显示 OpenCV 窗口

使用 `ssh -X`，或按第 6 节使用 `--headless`。完整应用部署时可使用默认的 `no_preview:=true`。

## 12. 详细文档

- 标定算法和参数：`calib/README.md`
- 检测节点与服务：`vison_topic/README.md`
- 坐标变换与安全门禁：`handeye_bridge/README.md`

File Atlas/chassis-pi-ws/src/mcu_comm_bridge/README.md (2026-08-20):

# mcu_comm_bridge 说明

本包负责 pi 与 mcu 之间的串口协议桥接

它把 mcu 的二进制协议转换成 ROS2 话题和服务，也把 pi 端控制服务转换成 mcu 能识别的二进制控制帧

## 一，包定位

本包是底层通信桥，不是任务管理器

负责

```text
解析 MCU_STATUS
解析 MCU_IMU
解析 MCU_ODOM
解析 MCU_ARM_STATE
发布 /mcu/status
发布 /mcu/auto_task_event
发布 /odom
发布 /imu
发布 /arm/joint_states
发布 /arm/pose
发布 /arm/pose_position
订阅 /motor_cmd_vel 并发送 PI_CONTROL 底盘部分
提供机械臂目标服务并发送 PI_CONTROL arm 部分
提供 PI 端末端吸盘服务并发送 PI_CONTROL suction 部分
提供任务结果服务并发送 PI_MISSION_EVENT
提供急停服务并发送 PI_ESTOP
发送 PI_HEARTBEAT
```

不负责

```text
不请求 mcu 进入 AutoPi
不实现自动任务流程
不执行导航
不执行视觉
不执行授粉动作序列
不根据业务逻辑判断 DONE 或 FAIL
```

## 二，与协议的关系

本包遵守 `comms_protocol.md` 中的约束

关键约束

```text
mcu 是状态机唯一所有者
pi 不具备切换 mcu 模式的线协议权限
AutoPi 的启动真值来自 MCU_STATUS.app_state 和 auto_start_latched
DONE 和 FAIL 只通过 PI_MISSION_EVENT 上报
clear/reset 只能由遥控器手势触发
```

## 三，发布话题

### /mcu/status

类型

```text
mcu_comm_bridge/msg/McuStatus
```

用途

```text
持续发布 mcu 状态，ready 位，在线位，故障信息，自动启动锁存
```

QoS 建议

```text
可靠
只保留最新一帧
瞬态本地
```

后启动的任务节点可以立即拿到最近一次 mcu 状态

### /mcu/auto_task_event

类型

```text
mcu_comm_bridge/msg/AutoTaskEvent
```

用途

```text
把 auto_start_latched 和 app_state 的边沿变化转换为一次性 START 或 RESET
```

事件

```text
EVENT_START
EVENT_RESET
```

注意

```text
这个话题不能使用瞬态本地
避免新订阅者把已发布的 START 当成新任务
```

### /odom

类型

```text
nav_msgs/msg/Odometry
```

来源

```text
MCU_ODOM
```

用途

```text
伪导航后端使用该话题闭环移动
```

### /imu

类型

```text
sensor_msgs/msg/Imu
```

来源

```text
MCU_IMU
```

### /arm/joint_states

类型

```text
sensor_msgs/msg/JointState
```

来源

```text
MCU_ARM_STATE 中的五个关节角
```

### /arm/pose

类型

```text
geometry_msgs/msg/PoseStamped
```

来源

```text
MCU_ARM_STATE 中末端位姿
```

### /arm/pose_position

类型

```text
geometry_msgs/msg/PointStamped
```

用途

```text
手眼标定工具和视觉授粉后端可使用该话题读取末端位置
```

## 四，订阅话题

### /motor_cmd_vel

类型

```text
geometry_msgs/msg/Twist
```

用途

```text
接收总任务状态机安全门控后的最终底盘速度
```

注意

```text
导航后端不能直接发布 /motor_cmd_vel
导航后端应发布 /atlas/navigation/cmd_vel
由 atlas_mission_manager 决定是否转发
```

## 五，服务接口

### /mcu/set_brake

用途

```text
请求底盘刹车或解除刹车
```

### /mcu/set_arm_joints

用途

```text
发送五关节目标
```

说明

```text
服务成功只表示命令写入串口，不表示 mcu 已执行完成
上层必须通过 /arm/joint_states 判断到位
```

### /mcu/set_arm_position

用途

```text
发送末端位置目标 x，y，z
```

说明

```text
服务成功只表示命令写入串口，不表示 IK 成功或动作完成
上层必须通过 /arm/pose_position 判断是否到位
```

### /mcu/set_suction

类型

```text
std_srvs/srv/SetBool
```

用途

```text
PI 端显式控制末端吸盘
data=true  打开吸盘
data=false 关闭吸盘
```

约束

```text
默认 require_auto_pi_for_suction=true，只有 MCU 处于 AutoPi 时服务才会下发吸盘命令
如果只是台架调试吸盘，可在 mcu_comm_bridge.yaml 中临时改成 false
```

机械臂目标服务的请求中也新增了两个字段：

```text
bool suction_valid   # true 表示本次机械臂目标同时携带吸盘命令
bool suction_enable  # suction_valid=true 时生效
```

当 suction_valid=false 时，本帧不改变吸盘状态

### /mcu/report_mission_result

用途

```text
pi 上报任务 DONE 或 FAIL
```

约束

```text
DONE 后 mcu 进入 Finished
FAIL 后 mcu 进入 recoverable Fault
DONE 和 FAIL 都不会清除 auto_start_latched
下一轮必须通过遥控器 clear/reset 手势解锁
```

### /mcu/estop

用途

```text
pi 主动发送急停事件
```

## 六，配置文件

配置文件

```text
config/mcu_comm_bridge.yaml
```

重点字段

| 字段 | 说明 |
|---|---|
| `port` | 串口设备路径 |
| `baudrate` | 串口波特率 |
| `publish_tf` | 是否发布 odom 到 base_footprint 的坐标变换 |
| `cmd_vel_timeout_ms` | 底盘速度超时时间 |
| `control_rate_hz` | PI_CONTROL 发送频率 |
| `arm_command_repeat_count` | 机械臂目标重复发送次数 |
| `suction_service` | PI 端末端吸盘服务名 |
| `require_auto_pi_for_suction` | 是否要求 AutoPi 才允许吸盘服务生效 |
| `mission_event_repeat_count` | DONE 或 FAIL 重复发送次数 |
| `auto_ack_start_sensor_event` | 是否自动确认未来启动传感器事件 |

## 七，单独启动

```bash
ros2 launch mcu_comm_bridge mcu_comm_bridge.launch.py
```

## 八，联调检查

确认 mcu 状态

```bash
ros2 topic echo /mcu/status \
  --qos-reliability reliable \
  --qos-durability transient_local
```

确认里程计

```bash
ros2 topic hz /odom
ros2 topic echo /odom
```

确认机械臂反馈

```bash
ros2 topic hz /arm/joint_states
ros2 topic echo /arm/pose_position
```

确认刹车服务

```bash
ros2 service call /mcu/set_brake std_srvs/srv/SetBool "{data: true}"
```

确认 PI 端吸盘服务

```bash
ros2 service call /mcu/set_suction std_srvs/srv/SetBool "{data: true}"
ros2 service call /mcu/set_suction std_srvs/srv/SetBool "{data: false}"
```

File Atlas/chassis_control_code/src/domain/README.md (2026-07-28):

# domain SDK 基本说明

> `sdks/domain/` 提供与真实硬件无关的领域算法和机构模型

---

## 1. 模块定位

domain 模块只描述数学模型、坐标系、机构参数、运动学和控制量转换；它不应直接接触 CAN/UART/GPIO，也不应依赖某个芯片平台

---

## 2. 当前模块

| 模块 | 文件 | 说明 |
|---|---|---|
| six_dof_arm_kine | `six_dof_arm_kine.h` / `six_dof_arm_kine.c` | 六轴串联机械臂 FK/IK、RPY/四元数转换 |
| steer_wheel_kine | `steer_wheel_kine.h` / `steer_wheel_kine.c` | 四舵轮底盘正逆运动学 |

---

## 3. 单位和坐标约定

| 类型 | 默认单位 |
|---|---|
| 长度 | `m`，除非接口注释明确写 `mm` |
| 角度 | `rad`，除非接口注释明确写 `deg` |
| 线速度 | `m/s` |
| 角速度 | `rad/s` |
| 关节角 | `rad` |
| 时间 | `s` 或 `ms`，由字段名和注释明确 |

坐标系、正方向、轮序、关节序号和解算失败条件必须写在 public header 或 README 中

---

## 4. 设计约束

- public header 不包含 HAL/FSP/CubeMX/CMSIS 头文件
- 不直接调用 platform、device 或真实外设
- 输入输出必须明确单位、坐标系和范围
- 初始化标志、是否启用等二值状态统一使用 `bool`，public header 需要自行包含 `<stdbool.h>`
- 初始化参数必须做合法性检查
- 解算失败应返回明确错误码，而不是只输出无效数据
- 能在 PC 上测试的模块应优先写边界测试和典型工况测试

---

## 5. 新增 domain 模块检查表

- [ ] 模型参数说明完整
- [ ] 坐标系和正方向明确
- [ ] 输入输出单位明确
- [ ] 输入输出范围明确
- [ ] 失败条件明确
- [ ] 不依赖 HAL/FSP/CubeMX
- [ ] 有最小 example 或 PC 测试样例

---

## 6. 后续补充方向

- angle normalize
- chassis limiter
- trajectory profile
- coordinate transform
- ackermann kinematics
- wheel-rail chassis model
- unit conversion helper

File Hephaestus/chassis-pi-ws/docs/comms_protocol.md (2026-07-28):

# MCU / PC / Pi 通信协议说明

> 文档定位：本文件是 `PC <-> MCU` 与 `Pi <-> MCU` 的统一协议及行为约束
>

---

## 1. 协议目标

本协议用于统一 `PC <-> MCU` 与 `Pi <-> MCU` 的通信格式和控制边界，目标如下：

1. 所有串口通信统一使用同一套二进制帧格式
2. `pc_comms` 与 `pi_comms` 只负责通信、校验、解析、缓存与发送，不直接控制底盘、机械臂或状态机
3. MCU 是系统状态机、模式切换和全自动任务启动权的唯一拥有者
4. Pi 不得主动请求 MCU 进入 `AutoPi`；Pi 通过 `MCU_STATUS` 被动获知状态和任务锁存标志
5. 高频连续控制量、一次性动作和跨状态锁存量必须明确区分
6. 通信错误原则上只丢帧、统计和限频告警，不直接进入 `Fault`
7. 所有消息必须明确方向、payload 长度、字节偏移、数据类型、单位、消费语义和权限边界

---

## 2. 总体职责与通信关系

### 2.1 PC -> MCU

PC 负责：

1. 发送 PC 心跳
2. 发送主臂五个关节角和末端开关状态

### 2.2 Pi -> MCU

Pi 负责：

1. 在 `AutoPi` 下发送高频底盘控制
2. 发送机械臂目标和一次性机械臂动作
3. 发送一次性 yaw 动作
4. 上报任务完成或任务失败
5. 发送急停事件
6. 对 MCU 需要 ACK 的一次性事件发送 ACK
7. 持续发送 Pi 心跳

### 2.3 MCU -> Pi

MCU 负责：

1. 周期发送 `MCU_STATUS`
2. 周期发送 IMU、里程计和机械臂状态
3. 在 `MCU_STATUS` 中发送当前状态机状态和 `auto_start_latched`
4. 发送需要 ACK 的一次性事件
5. 发送 ACK
6. 预留故障即时事件

### 2.4 全自动任务启动权

当前阶段仅考虑遥控器启动：

```text
遥控器产生有效自动启动边沿
        ↓
MCU 检查状态、Pi 在线、底盘和里程计 ready
        ↓
MCU 将 auto_start_latched 从 0 置为 1
        ↓
MCU 执行 Idle -> AutoPi
        ↓
MCU 通过 MCU_STATUS 持续通知 Pi
        ↓
Pi 检测到 auto_start_latched=1 且 app_state=AutoPi
        ↓
Pi 只产生一次 START 事件
```

下一轮任务不能通过释放自动挡直接解锁，必须执行遥控器清理手势：

```text
SWC 置高 + VRA 置低 + VRB 置低
        ↓
MCU 将 auto_start_latched 从 1 清为 0
        ↓
MCU 清理自动任务控制上下文
        ↓
Pi 检测到 1 -> 0
        ↓
Pi 清理本地自动任务上下文并产生一次 RESET 事件
```

---

## 3. 通用二进制帧格式

统一帧格式：

```text
SOF0     1 byte   0xA5
SOF1     1 byte   0x5A
LEN_H    1 byte   body length high byte
LEN_L    1 byte   body length low byte
VER      1 byte   protocol version
MSG_ID   1 byte   message id
SEQ      1 byte   sequence number
FLAGS    1 byte   flags
PAYLOAD  N byte   payload
CRC_H    1 byte   CRC16 high byte
CRC_L    1 byte   CRC16 low byte
```

| 帧偏移 | 长度 | 字段 | 说明 |
|---:|---:|---|---|
| 0 | 1 | `SOF0` | 固定 `0xA5` |
| 1 | 1 | `SOF1` | 固定 `0x5A` |
| 2 | 1 | `LEN_H` | body 长度高字节 |
| 3 | 1 | `LEN_L` | body 长度低字节 |
| 4 | 1 | `VER` | 当前固定 `0x01` |
| 5 | 1 | `MSG_ID` | 消息 ID |
| 6 | 1 | `SEQ` | 帧序号 |
| 7 | 1 | `FLAGS` | 标志位 |
| 8 | N | `PAYLOAD` | 业务数据 |
| 8 + N | 1 | `CRC_H` | CRC16 高字节 |
| 9 + N | 1 | `CRC_L` | CRC16 低字节 |

约定：

1. `LEN` 表示 `VER + MSG_ID + SEQ + FLAGS + PAYLOAD` 的总长度
2. `body_len = 4 + payload_len`
3. `frame_len = 10 + payload_len`
4. `LEN` 使用大端格式
5. `CRC` 使用大端格式
6. payload 内多字节字段使用小端格式
7. `SEQ` 为 `uint8_t`，按 `0 -> 255 -> 0` 循环
8. `FLAGS bit0 = NEED_ACK`，其余位保留
9. 高频周期帧和高频控制帧不使用 ACK

### 3.1 CRC 参数

CRC 必须使用以下完整参数：

```text
Name:       CRC-16/CCITT-FALSE
Polynomial: 0x1021
Init:       0xFFFF
RefIn:      false
RefOut:     false
XorOut:     0x0000
Check:      0x29B1 for ASCII "123456789"
```

CRC 覆盖范围：

```text
SOF0 + SOF1 + LEN_H + LEN_L + VER + MSG_ID + SEQ + FLAGS + PAYLOAD
```

CRC 不覆盖末尾的 `CRC_H / CRC_L` 自身

---

## 4. 字节序、类型与单位

### 4.1 字节序

1. 帧级 `LEN` 和 `CRC` 使用大端
2. payload 内 `uint16_t / int16_t / uint32_t / int32_t` 使用小端
3. 不直接传输 IEEE 754 `float`
4. 布尔字段在线协议中使用 `uint8_t`，合法值为 `0` 或 `1`

### 4.2 单位

| 物理量 | 常用类型 | 线单位 | 换算 |
|---|---|---|---|
| 时间戳 | `uint32_t` | `ms` | MCU/Pi/PC 各自单调时钟，不是 Unix 时间 |
| 角度 | `int32_t` | `urad` | `rad = urad × 1e-6` |
| 角速度 | `int32_t` | `urad/s` | `rad/s = urad/s × 1e-6` |
| PI_CONTROL 底盘角速度 | `int16_t` | `mrad/s` | `rad/s = mrad/s × 1e-3` |
| PI_CONTROL 线速度 | `int16_t` | `mm/s` | `m/s = mm/s × 1e-3` |
| ODOM 线速度 | `int32_t` | `mm/s` | `m/s = mm/s × 1e-3` |
| 位置 | `int32_t` | `mm` | `m = mm × 1e-3` |
| 加速度 | `int32_t` | `mm/s²` | `m/s² = mm/s² × 1e-3` |
| 四元数 | `int16_t` | Q15 | `q = q15 / 32767.0` |

---

## 5. 消息 ID 总表

### 5.1 PC -> MCU

| MSG_ID | 名称 | payload 长度 | 语义 |
|---:|---|---:|---|
| `0x10` | `PC_HEARTBEAT` | 0 | PC 心跳 |
| `0x11` | `PC_MASTER_JOINTS` | 25 | 主臂关节角和末端开关 |

### 5.2 MCU -> Pi

| MSG_ID | 名称 | payload 长度 | 语义 |
|---:|---|---:|---|
| `0x21` | `MCU_STATUS` | 16 | MCU 状态、故障和自动任务锁存标志 |
| `0x22` | `MCU_START_SENSOR_EVENT` | 8 | 启动传感器事件，当前阶段保留 |
| `0x23` | `MCU_ACK` | 4 | MCU ACK |
| `0x24` | `MCU_FAULT_EVENT` | 8 | 故障即时事件，当前预留 |
| `0x25` | `MCU_IMU` | 48 | IMU 周期帧，100 Hz |
| `0x26` | `MCU_ODOM` | 32 | 局部里程计周期帧，50 Hz |
| `0x27` | `MCU_ARM_STATE` | 48 | 机械臂状态周期帧，50 Hz |

### 5.3 Pi -> MCU

| MSG_ID | 名称 | payload 长度 | 语义 |
|---:|---|---:|---|
| `0x30` | `PI_HEARTBEAT` | 0 | Pi 心跳 |
| `0x31` | `PI_CONTROL` | 38 | 底盘连续控制和机械臂目标 |
| `0x40` | `PI_ARM_ACTION` | 8 | 一次性机械臂动作 |
| `0x41` | `PI_YAW_ACTION` | 12 | 一次性 yaw 动作 |
| `0x42` | `PI_MISSION_EVENT` | 8 | 任务完成或失败 |
| `0x43` | `PI_ESTOP` | 8 | 急停事件 |
| `0x44` | `PI_ACK` | 4 | Pi ACK |

Pi 不具备切换 MCU 模式的线协议权限

---

## 6. PC -> MCU 消息

### 6.1 PC_HEARTBEAT

```text
Direction: PC -> MCU
MSG_ID:    0x10
Payload:   empty
```

语义：

1. 更新 PC 在线状态
2. 更新最近一次有效接收时间
3. 不修改主臂关节角缓存

推荐频率：

```text
1 Hz
```

当前 PC 工具默认：

```text
MCU baudrate: 921600
Heartbeat:    1 Hz
```

### 6.2 PC_MASTER_JOINTS

```text
Direction:      PC -> MCU
MSG_ID:         0x11
Payload length: 25 bytes
```

| payload 偏移 | 长度 | 类型 | 字段 | 单位 |
|---:|---:|---|---|---|
| 0 | 4 | `uint32_t` | `stamp_ms` | `ms` |
| 4 | 4 | `int32_t` | `q0_urad` | `urad` |
| 8 | 4 | `int32_t` | `q1_urad` | `urad` |
| 12 | 4 | `int32_t` | `q2_urad` | `urad` |
| 16 | 4 | `int32_t` | `q3_urad` | `urad` |
| 20 | 4 | `int32_t` | `q4_urad` | `urad` |
| 24 | 1 | `uint8_t` | `end_switch` | `0` 未触发，`1` 触发 |

语义：

1. `pc_comms` 只解析并缓存
2. MCU 将五个 `urad` 转换为 `rad`
3. `end_switch` 来自主臂末端设备
4. 该消息使用连续值的 `get + fresh timeout` 语义

权限约束：

1. 仅允许在 `Manual + ManualChassisPcArm` 下被 app 层消费
2. 离开 `ManualChassisPcArm` 时必须清除主臂缓存
3. PC 离线不得影响不依赖 PC 的其他手动模式或 `Idle`

推荐频率：

```text
30 Hz ~ 100 Hz
当前 PC 工具默认 50 Hz
```

---

## 7. Pi -> MCU 消息

### 7.1 PI_HEARTBEAT

```text
Direction: Pi -> MCU
MSG_ID:    0x30
Payload:   empty
```

语义：

1. 更新 Pi 在线状态
2. 更新最近一次有效接收时间
3. 不修改普通控制缓存
4. Pi 自动任务上下文复位后仍必须继续发送心跳

推荐频率：

```text
1 Hz
```

MCU 当前在线超时：

```text
3000 ms
```

### 7.2 PI_CONTROL

```text
Direction:      Pi -> MCU
MSG_ID:         0x31
Payload length: 38 bytes
```

该帧同时承载：

1. 底盘连续控制
2. 机械臂离散目标命令
3. PI 端末端吸盘条件控制

三者消费语义不同：

```text
chassis 部分：get + fresh timeout
arm 部分：command_seq 去重 + take/consume
suction 部分：显式 suction_valid 才消费；可独立控制，也可随 arm 目标同帧下发
```

#### 7.2.1 固定头部和底盘字段

| payload 偏移 | 长度 | 类型 | 字段 | 单位 / 说明 |
|---:|---:|---|---|---|
| 0 | 4 | `uint32_t` | `stamp_ms` | Pi 单调时钟 `ms` |
| 4 | 1 | `uint8_t` | `control_mask` | 有效位 |
| 5 | 1 | `uint8_t` | `arm_mode` | 机械臂目标模式 |
| 6 | 2 | `uint16_t` | `command_seq` | 机械臂命令去重序号 |
| 8 | 2 | `int16_t` | `vx_mm_s` | `mm/s` |
| 10 | 2 | `int16_t` | `vy_mm_s` | `mm/s` |
| 12 | 2 | `int16_t` | `wz_mrad_s` | `mrad/s` |
| 14 | 20 | union | `arm_target[5]` | 由 `arm_mode` 决定 |
| 34 | 2 | `uint16_t` | `arm_speed_mrad_s` | `mrad/s` |
| 36 | 1 | `uint8_t` | `suction_enable` | `control_mask.bit2=1` 时有效，0=关闭，1=打开 |
| 37 | 1 | `uint8_t` | `reserved` | 必须填 0 |

`control_mask`：

| bit | 名称 | 说明 |
|---:|---|---|
| bit0 | `chassis_valid` | 本帧更新底盘控制缓存 |
| bit1 | `arm_valid` | 本帧包含机械臂目标 |
| bit2 | `suction_valid` | 本帧包含 PI 端末端吸盘命令 |
| bit3 | `brake_request` | 请求底盘刹车 |
| bit4 ~ bit7 | reserved | 必须为 0 |

注意：

1. `arm_valid` 不只表示关节角，也可表示末端 Pose、位置或姿态目标
2. `suction_valid=0` 表示本帧不改变吸盘状态，不再强制关闭吸盘
3. `suction_valid=1` 且 `arm_valid=0` 时表示独立吸盘命令；`suction_valid=1` 且 `arm_valid=1` 时表示机械臂目标附带吸盘命令
4. 某个 valid bit 为 0，不表示清除该部分旧缓存
5. 旧缓存是否失效由 fresh timeout 或状态切换清理决定

#### 7.2.2 arm_mode

| 值 | 名称 | 说明 |
|---:|---|---|
| 0 | `NONE` | 本帧不发送机械臂目标 |
| 1 | `JOINTS` | 五关节目标 |
| 2 | `POSE_5D` | `x/y/z/pitch/yaw` |
| 3 | `POSITION` | `x/y/z` |
| 4 | `ORIENTATION_2D` | `pitch/yaw` |

#### 7.2.3 JOINTS 布局

`arm_mode = 1`

| 偏移 | 类型 | 字段 | 单位 |
|---:|---|---|---|
| 14 | `int32_t` | `q0_urad` | `urad` |
| 18 | `int32_t` | `q1_urad` | `urad` |
| 22 | `int32_t` | `q2_urad` | `urad` |
| 26 | `int32_t` | `q3_urad` | `urad` |
| 30 | `int32_t` | `q4_urad` | `urad` |

#### 7.2.4 POSE_5D 布局

`arm_mode = 2`

| 偏移 | 类型 | 字段 | 单位 |
|---:|---|---|---|
| 14 | `int32_t` | `x_mm` | `mm` |
| 18 | `int32_t` | `y_mm` | `mm` |
| 22 | `int32_t` | `z_mm` | `mm` |
| 26 | `int32_t` | `pitch_urad` | `urad` |
| 30 | `int32_t` | `yaw_urad` | `urad` |

#### 7.2.5 POSITION 布局

`arm_mode = 3`

| 偏移 | 类型 | 字段 | 单位 / 说明 |
|---:|---|---|---|
| 14 | `int32_t` | `x_mm` | `mm` |
| 18 | `int32_t` | `y_mm` | `mm` |
| 22 | `int32_t` | `z_mm` | `mm` |
| 26 | `int32_t` | reserved | 必须填 0 |
| 30 | `int32_t` | reserved | 必须填 0 |

#### 7.2.6 ORIENTATION_2D 布局

`arm_mode = 4`

| 偏移 | 类型 | 字段 | 单位 / 说明 |
|---:|---|---|---|
| 14 | `int32_t` | `pitch_urad` | `urad` |
| 18 | `int32_t` | `yaw_urad` | `urad` |
| 22 | `int32_t` | reserved | 必须填 0 |
| 26 | `int32_t` | reserved | 必须填 0 |
| 30 | `int32_t` | reserved | 必须填 0 |

#### 7.2.7 command_seq 语义

1. 每个新的机械臂目标分配一个 `uint16_t command_seq`
2. 同一目标的重发帧必须使用相同 `command_seq`
3. MCU 对相同 `command_seq` 只允许消费一次
4. `command_seq` 自然回绕
5. `command_seq` 只用于机械臂目标去重，不用于底盘连续控制
6. 当前 Pi bridge 建议同一机械臂目标重复发送 3 帧，提高串口瞬态丢帧下的到达概率

#### 7.2.8 权限和超时

1. `PI_CONTROL` 仅允许在 `AutoPi` 下执行
2. 底盘控制 fresh timeout 当前为 `200 ms`
3. 机械臂控制 fresh timeout 当前为 `200 ms`
4. 无新鲜底盘命令时，MCU 必须停止或刹车
5. 离开 `AutoPi`、执行遥控器清理手势或 `auto_start_latched` 复位时，必须清除普通 Pi 控制缓存
6. 清普通控制缓存不得清除 pending EStop

推荐发送频率：

```text
20 Hz ~ 50 Hz
当前 Pi bridge 默认 50 Hz
```

### 7.3 PI_ARM_ACTION

```text
Direction:      Pi -> MCU
MSG_ID:         0x40
Payload length: 8 bytes
Consumption:    take/consume
```

| 偏移 | 长度 | 类型 | 字段 | 说明 |
|---:|---:|---|---|---|
| 0 | 4 | `uint32_t` | `stamp_ms` | 时间戳 |
| 4 | 1 | `uint8_t` | `action` | 动作类型 |
| 5 | 1 | `uint8_t` | reserved | 必须填 0 |
| 6 | 2 | `uint16_t` | `sequence_id` | 序列动作编号 |

| action | 名称 |
|---:|---|
| 1 | `ARM_ENABLE` |
| 2 | `ARM_STOP` |
| 3 | `ARM_SEQUENCE` |

合法动作被缓存为 pending action，app 层读取后立即清除

### 7.4 PI_YAW_ACTION

```text
Direction:      Pi -> MCU
MSG_ID:         0x41
Payload length: 12 bytes
Consumption:    take/consume
```

| 偏移 | 长度 | 类型 | 字段 | 单位 / 说明 |
|---:|---:|---|---|---|
| 0 | 4 | `uint32_t` | `stamp_ms` | `ms` |
| 4 | 1 | `uint8_t` | `action` | 动作类型 |
| 5 | 3 | `uint8_t[3]` | reserved | 必须填 0 |
| 8 | 4 | `int32_t` | `target_yaw_urad` | `urad` |

| action | 名称 |
|---:|---|
| 1 | `HOLD_ENABLE` |
| 2 | `HOLD_DISABLE` |
| 3 | `TARGET_SET` |

连续旋转速度仍通过 `PI_CONTROL.wz_mrad_s` 表达

### 7.5 PI_MISSION_EVENT

```text
Direction:      Pi -> MCU
MSG_ID:         0x42
Payload length: 8 bytes
Consumption:    take/consume
```

| 偏移 | 长度 | 类型 | 字段 | 说明 |
|---:|---:|---|---|---|
| 0 | 4 | `uint32_t` | `stamp_ms` | 时间戳 |
| 4 | 1 | `uint8_t` | `event` | 任务事件 |
| 5 | 1 | `uint8_t` | reserved | 必须填 0 |
| 6 | 2 | `int16_t` | `code` | 失败码，DONE 时填 0 |

| event | 名称 | MCU 行为 |
|---:|---|---|
| 1 | `DONE` | `AutoPi -> Finished` |
| 2 | `FAIL` | 进入 recoverable `Fault` |

关键约束：

1. `DONE` 不清除 `auto_start_latched`
2. `FAIL` 不清除 `auto_start_latched`
3. 任务结束后仍需遥控器清理手势，才能允许下一轮启动
4. 非 `AutoPi` 状态下收到任务事件，应忽略并统计或限频告警

### 7.6 PI_ESTOP

```text
Direction:      Pi -> MCU
MSG_ID:         0x43
Payload length: 8 bytes
Consumption:    global take/consume
```

| 偏移 | 长度 | 类型 | 字段 | 说明 |
|---:|---:|---|---|---|
| 0 | 4 | `uint32_t` | `stamp_ms` | 时间戳 |
| 4 | 1 | `uint8_t` | `reason` | 急停原因 |
| 5 | 3 | `uint8_t[3]` | reserved | 必须填 0 |

约束：

1. 任意状态全局生效
2. 收到后 MCU 必须进入 `EStop`
3. 普通清故障不能解除 `EStop`
4. `pi_comms_clear_controls()` 不得清除 pending EStop
5. 遥控器清理手势可将 `auto_start_latched` 清为 0，但 MCU 必须继续保持 `EStop`

### 7.7 PI_ACK

```text
Direction:      Pi -> MCU
MSG_ID:         0x44
Payload length: 4 bytes
```

| 偏移 | 长度 | 类型 | 字段 | 说明 |
|---:|---:|---|---|---|
| 0 | 1 | `uint8_t` | `ack_msg_id` | 被确认的消息 ID |
| 1 | 1 | `uint8_t` | `ack_seq` | 被确认帧 SEQ |
| 2 | 2 | `uint16_t` | `code` | 结果码，0 表示成功 |

ACK 不匹配只丢弃、统计和限频告警，不进入 `Fault`

---

## 8. MCU -> Pi 消息

### 8.1 MCU_STATUS

```text
Direction:      MCU -> Pi
MSG_ID:         0x21
Payload length: 16 bytes
Recommended:    10 Hz
ACK:            no
```

#### 8.1.1 payload 布局

| 偏移 | 长度 | 类型 | 字段 | 说明 |
|---:|---:|---|---|---|
| 0 | 4 | `uint32_t` | `stamp_ms` | MCU 单调时钟 |
| 4 | 1 | `uint8_t` | `app_state` | 状态机状态 |
| 5 | 1 | `uint8_t` | `manual_mode` | Manual 子模式 |
| 6 | 1 | `uint8_t` | `ready_flags` | ready 位图 |
| 7 | 1 | `uint8_t` | `online_flags` | 在线和故障位图 |
| 8 | 1 | `uint8_t` | `fault_source` | 故障来源 |
| 9 | 1 | `uint8_t` | `fault_level` | 故障等级 |
| 10 | 2 | `int16_t` | `fault_code` | 故障码 |
| 12 | 1 | `uint8_t` | `auto_start_latched` | 全自动任务启动锁存，合法值 0/1 |
| 13 | 3 | `uint8_t[3]` | reserved | 必须填 0 |

完整帧长度：

```text
26 bytes
```

#### 8.1.2 app_state

| 值 | 状态 |
|---:|---|
| 0 | `IDLE` |
| 1 | `MANUAL` |
| 2 | `AUTO_PI` |
| 3 | `FAULT` |
| 4 | `ESTOP` |
| 5 | `FINISHED` |

#### 8.1.3 manual_mode

| 值 | 模式 |
|---:|---|
| 0 | `CHASSIS_PC_ARM` |
| 1 | `ARM_FS` |

`manual_mode` 在非 Manual 状态下仅表示最近一次配置，不代表该模式正在执行

#### 8.1.4 ready_flags

| bit | 名称 |
|---:|---|
| bit0 | `chassis_ready` |
| bit1 | `arm_ready` |
| bit2 | `odom_ready` |
| bit3 | `remote_ready` |
| bit4 | `pc_ready` |
| bit5 | `pi_ready` |
| bit6 ~ bit7 | reserved |

#### 8.1.5 online_flags

| bit | 名称 |
|---:|---|
| bit0 | `remote_online` |
| bit1 | `pc_online` |
| bit2 | `pi_online` |
| bit3 | `has_fault` |
| bit4 | `estop_active` |
| bit5 ~ bit7 | reserved |

#### 8.1.6 fault_source

| 值 | 名称 |
|---:|---|
| 0 | `NONE` |
| 1 | `CHASSIS` |
| 2 | `ODOM` |
| 3 | `ARM` |
| 4 | `REMOTE` |
| 5 | `PC_LINK` |
| 6 | `PI_LINK` |
| 7 | `PI_MISSION` |
| 8 | `COMMAND` |
| 9 | `SYSTEM` |

#### 8.1.7 fault_level

| 值 | 名称 |
|---:|---|
| 0 | `NONE` |
| 1 | `WARN` |
| 2 | `DEGRADE` |
| 3 | `RECOVERABLE` |
| 4 | `FATAL` |

#### 8.1.8 auto_start_latched

| 值 | 含义 |
|---:|---|
| 0 | 当前没有已锁存的启动事件，允许准备下一轮任务 |
| 1 | MCU 已接受过一轮全自动启动，清理手势前禁止再次启动 |

要求：

1. MCU 上电初始化为 `0`
2. 只有启动前置条件全部通过，且 MCU 接受一次有效遥控器启动边沿时，才能置为 `1`
3. `DONE`、`FAIL`、Pi 掉线、人工切入 Manual 或自动挡释放均不得自动将其清为 `0`
4. 只有遥控器 clear/reset 手势可以将其清为 `0`
5. 标志清零时，MCU 必须清理自动任务控制上下文
6. Pi 必须检测边沿，不得在每帧看到 0 时反复清理
7. Pi 收到非法值时应增加协议错误统计，并按 `1` 处理，防止误允许新任务

### 8.2 MCU_IMU

```text
Direction:      MCU -> Pi
MSG_ID:         0x25
Payload length: 48 bytes
Recommended:    100 Hz
ACK:            no
```

| 偏移 | 长度 | 类型 | 字段 | 单位 |
|---:|---:|---|---|---|
| 0 | 4 | `uint32_t` | `stamp_ms` | `ms` |
| 4 | 2 | `uint16_t` | `status_flags` | 位图 |
| 6 | 2 | `uint16_t` | `sequence_count` | 递增计数 |
| 8 | 4 | `int32_t` | `acc_x_mm_s2` | `mm/s²` |
| 12 | 4 | `int32_t` | `acc_y_mm_s2` | `mm/s²` |
| 16 | 4 | `int32_t` | `acc_z_mm_s2` | `mm/s²` |
| 20 | 4 | `int32_t` | `gyro_x_urad_s` | `urad/s` |
| 24 | 4 | `int32_t` | `gyro_y_urad_s` | `urad/s` |
| 28 | 4 | `int32_t` | `gyro_z_urad_s` | `urad/s` |
| 32 | 4 | `int32_t` | `roll_urad` | `urad` |
| 36 | 4 | `int32_t` | `pitch_urad` | `urad` |
| 40 | 4 | `int32_t` | `yaw_urad` | `urad` |
| 44 | 4 | `uint32_t` | reserved | 必须填 0 |

`status_flags`：

| bit | 名称 |
|---:|---|
| bit0 | `IMU_READY` |
| bit1 | `ACC_VALID` |
| bit2 | `GYRO_VALID` |
| bit3 | `ANGLE_VALID` |
| bit4 | `YAW_FUSED_WITH_CHASSIS` |
| bit5 | `BIAS_CORRECTED` |
| bit6 ~ bit15 | reserved |

说明：

1. `yaw_urad` 使用融合后的姿态 `angle.z`
2. 与 `MCU_ODOM.yaw_urad` 同源
3. Pi 不应把 MCU `stamp_ms` 直接解释成 ROS epoch

### 8.3 MCU_ODOM

```text
Direction:      MCU -> Pi
MSG_ID:         0x26
Payload length: 32 bytes
Recommended:    50 Hz
ACK:            no
```

| 偏移 | 长度 | 类型 | 字段 | 单位 / 坐标系 |
|---:|---:|---|---|---|
| 0 | 4 | `uint32_t` | `stamp_ms` | `ms` |
| 4 | 2 | `uint16_t` | `status_flags` | 位图 |
| 6 | 2 | `uint16_t` | `reset_counter` | 里程计复位计数 |
| 8 | 4 | `int32_t` | `x_mm` | odom，`mm` |
| 12 | 4 | `int32_t` | `y_mm` | odom，`mm` |
| 16 | 4 | `int32_t` | `yaw_urad` | odom，`urad` |
| 20 | 4 | `int32_t` | `vx_mm_s` | base_link，`mm/s` |
| 24 | 4 | `int32_t` | `vy_mm_s` | base_link，`mm/s` |
| 28 | 4 | `int32_t` | `wz_urad_s` | base_link，`urad/s` |

`status_flags`：

| bit | 名称 |
|---:|---|
| bit0 | `ODOM_READY` |
| bit1 | `POSE_VALID` |
| bit2 | `TWIST_VALID` |
| bit3 | `IMU_FUSED` |
| bit4 | `WHEEL_FUSED` |
| bit5 | `STATIC_DETECTED` |
| bit6 | `SLIP_SUSPECTED` |
| bit7 | `ODOM_RESET` |
| bit8 ~ bit15 | reserved |

### 8.4 MCU_ARM_STATE

```text
Direction:      MCU -> Pi
MSG_ID:         0x27
Payload length: 48 bytes
Recommended:    50 Hz
ACK:            no
```

| 偏移 | 长度 | 类型 | 字段 | 单位 / 说明 |
|---:|---:|---|---|---|
| 0 | 4 | `uint32_t` | `stamp_ms` | `ms` |
| 4 | 2 | `uint16_t` | `status_flags` | 有效位 |
| 6 | 2 | `uint16_t` | `sequence_count` | 递增计数 |
| 8 | 4 | `int32_t` | `q0_urad` | `urad` |
| 12 | 4 | `int32_t` | `q1_urad` | `urad` |
| 16 | 4 | `int32_t` | `q2_urad` | `urad` |
| 20 | 4 | `int32_t` | `q3_urad` | `urad` |
| 24 | 4 | `int32_t` | `q4_urad` | `urad` |
| 28 | 4 | `int32_t` | `x_mm` | `mm` |
| 32 | 4 | `int32_t` | `y_mm` | `mm` |
| 36 | 4 | `int32_t` | `z_mm` | `mm` |
| 40 | 2 | `int16_t` | `quat_x_q15` | `q / 32767.0` |
| 42 | 2 | `int16_t` | `quat_y_q15` | `q / 32767.0` |
| 44 | 2 | `int16_t` | `quat_z_q15` | `q / 32767.0` |
| 46 | 2 | `int16_t` | `quat_w_q15` | `q / 32767.0` |

`status_flags`：

| bit | 名称 |
|---:|---|
| bit0 | `ARM_READY` |
| bit1 | `JOINT_VALID` |
| bit2 | `FK_VALID / POSE_VALID` |
| bit3 ~ bit15 | reserved |

Pose 表示末端坐标系相对于 `arm_base_link` 的位姿，四元数顺序固定为 `x/y/z/w`

### 8.5 MCU_START_SENSOR_EVENT

```text
Direction:      MCU -> Pi
MSG_ID:         0x22
Payload length: 8 bytes
Default flags:  NEED_ACK
```

| 偏移 | 长度 | 类型 | 字段 | 说明 |
|---:|---:|---|---|---|
| 0 | 4 | `uint32_t` | `stamp_ms` | 时间戳 |
| 4 | 1 | `uint8_t` | `sensor_id` | 传感器 ID |
| 5 | 1 | `uint8_t` | `event_type` | 事件类型 |
| 6 | 2 | `uint16_t` | `event_value` | 事件值 |

当前阶段说明：

1. 当前仅使用遥控器启动，不使用该消息表达遥控器自动启动
2. 遥控器任务启动由 `MCU_STATUS.app_state + auto_start_latched` 表达
3. 本消息保留给未来光电传感器或外部 IO 触发源
4. MCU 内部维护单槽 pending event
5. 未收到 ACK 时每 `100 ms` 重发
6. ACK 超时不阻塞主循环，不进入 `Fault`

### 8.6 MCU_ACK

```text
Direction:      MCU -> Pi
MSG_ID:         0x23
Payload length: 4 bytes
```

| 偏移 | 长度 | 类型 | 字段 |
|---:|---:|---|---|
| 0 | 1 | `uint8_t` | `ack_msg_id` |
| 1 | 1 | `uint8_t` | `ack_seq` |
| 2 | 2 | `uint16_t` | `code` |

用于确认 Pi 的一次性动作或事件；当前主要保留统一格式和发送接口

### 8.7 MCU_FAULT_EVENT

```text
Direction:      MCU -> Pi
MSG_ID:         0x24
Payload length: 8 bytes
Status:         reserved
```

| 偏移 | 长度 | 类型 | 字段 |
|---:|---:|---|---|
| 0 | 4 | `uint32_t` | `stamp_ms` |
| 4 | 1 | `uint8_t` | `fault_source` |
| 5 | 1 | `uint8_t` | `fault_level` |
| 6 | 2 | `int16_t` | `fault_code` |

故障的持续真值仍以周期 `MCU_STATUS` 为准

---

## 9. 遥控器启动与 clear/reset 手势

### 9.1 遥控器通道约定

| 通道 | 含义 |
|---:|---|
| CH4 | `SWA` |
| CH5 | `SWB` |
| CH6 | `SWC` |
| CH7 | `SWD` |
| CH8 | `VRA` |
| CH9 | `VRB` |

当前代码中的语义常量：

```text
REMOTE_SW_HIGH = 1000
REMOTE_SW_CENTER = 1500
REMOTE_SW_LOW = 2000
REMOTE_AUTO_THRESHOLD = 1800
REMOTE_VR_LOW_THRESHOLD = 1200
```

注意：`HIGH/LOW` 是软件语义名称，FS-iA10B 原始数值方向可能与直觉相反

### 9.2 自动启动条件

当前遥控器全自动启动条件：

```text
remote_online == true
SWD == REMOTE_SW_HIGH
VRA >= REMOTE_AUTO_THRESHOLD
VRB >= REMOTE_AUTO_THRESHOLD
```

该条件只能生成一次边沿事件，不能作为持续电平命令

边沿规则：

1. MCU 上电时自动启动边沿默认未武装
2. 遥控器重新上线时自动启动边沿默认未武装
3. 必须先观察到一次“非自动启动条件”，才能武装
4. 从非自动条件进入自动条件时产生一次 pending 启动事件
5. 自动条件持续保持时不得重复产生事件
6. 自动条件释放后可以重新形成输入边沿，但若 `auto_start_latched=1`，app 层仍必须拒绝再次启动

### 9.3 clear/reset 条件

全自动任务复位与可恢复故障清理手势：

```text
remote_online == true
SWC == REMOTE_SW_HIGH
VRA <= REMOTE_VR_LOW_THRESHOLD
VRB <= REMOTE_VR_LOW_THRESHOLD
```

本修订不要求 `SWD` 处于特定位置

clear/reset 也使用边沿事件：

1. 第一次从非清理条件进入清理条件时产生一次事件
2. 持续保持该手势不得重复清理或刷日志
3. 离开该手势后重新武装
4. 遥控器离线时清除 pending，并重新进入未武装状态

### 9.4 启动接受条件

MCU 只在以下条件全部满足时接受启动：

```text
auto_start_latched == 0
app_state == IDLE
Pi online == true
chassis_ready == true
odom_ready == true
not ESTOP
没有阻止启动的 Fault
```

机械臂 ready 不作为仅底盘任务的强制启动条件

启动被拒绝时：

1. `auto_start_latched` 保持 0
2. MCU 保持 `Idle`
3. 不因启动条件不足直接进入 `Fault`
4. 输出限频拒绝原因
5. 操作员必须退出自动条件并重新触发边沿后才能重试

### 9.5 启动接受顺序

推荐顺序：

```text
1. app_control_stop_all()
2. pi_comms_clear_controls()
3. chassis_yaw_hold_reset()
4. auto_start_latched = 1
5. post SWITCH_TO_AUTO_PI
6. MCU_STATUS 持续发送 app_state=AutoPi, auto_start_latched=1
```

### 9.6 clear/reset 行为

收到一次有效 clear/reset 边沿后：

```text
1. auto_start_latched = 0
2. 清除 pending auto-start event
3. 清除 Pi 普通底盘控制缓存
4. 清除 Pi 普通机械臂目标和普通一次性动作
5. 清除普通 yaw action 和 yaw hold 上下文
6. 清除 pending mission event
7. 不清除 pending EStop
8. 停止底盘和机械臂
9. 按现有规则清除 recoverable Fault
10. 根据当前状态进入安全状态
```

不同状态下的行为：

| 当前状态 | clear/reset 后状态 | 说明 |
|---|---|---|
| `Idle` | `Idle` | 清上下文，保持安全停止 |
| `Manual` | `Manual` | 保持人工控制模式，仅清自动任务上下文 |
| `AutoPi` | `Idle` | 人工取消当前全自动任务 |
| `Finished` | `Idle` | 为下一轮任务解锁 |
| recoverable `Fault` | `Idle` | 清故障并解锁 |
| fatal `Fault` | `Fault` | 可清任务锁存，但不得清 fatal fault |
| `EStop` | `EStop` | 可清任务锁存和普通上下文，但不得解除急停 |

核心约束：

```text
任务完成 != 允许再次启动
任务失败 != 允许再次启动
释放自动条件 != 允许再次启动
人工切换 Manual != 允许再次启动

只有 clear/reset 手势可以使 auto_start_latched 从 1 变为 0
```

---

## 10. MCU 状态机权限和转换约束

### 10.1 状态所有权

1. MCU 是状态机唯一所有者
2. `pc_comms` 和 `pi_comms` 不判断状态机权限
3. app/runtime 层统一判断消息是否允许执行
4. Pi 不能通过通信协议请求进入 `AutoPi`

### 10.2 主要转换

| 来源 | 条件 / 事件 | 目标 |
|---|---|---|
| `Idle` | 遥控器 Manual 请求 | `Manual` |
| `Idle` | 有效自动启动事件被 MCU 接受 | `AutoPi` |
| `Manual` | 遥控器退出 Manual | `Idle` |
| `Manual` | EStop / Fault | `EStop / Fault` |
| `AutoPi` | 遥控器 Manual 抢占 | `Manual` |
| `AutoPi` | `PI_MISSION_EVENT.DONE` | `Finished` |
| `AutoPi` | `PI_MISSION_EVENT.FAIL` | `Fault` |
| `AutoPi` | Pi 离线或关键依赖失败 | recoverable `Fault` |
| `AutoPi` | clear/reset 手势 | `Idle` |
| `Finished` | clear/reset 手势 | `Idle` |
| recoverable `Fault` | clear/reset 手势 | `Idle` |
| 任意非 EStop | `PI_ESTOP` | `EStop` |

状态机底层即使支持其他转换，app/runtime 也不得绕过本节业务约束直接触发新的自动任务

### 10.3 人工抢占

1. 遥控器 Manual 请求优先于普通自动控制
2. `AutoPi -> Manual` 时必须立即清 Pi 普通控制缓存
3. 人工抢占不自动清除 `auto_start_latched`
4. 重新启动全自动任务前仍需 clear/reset 手势

---

## 11. Pi 端状态同步与 ROS2 映射

本节描述 Pi bridge 迭代后的行为它不新增线协议消息

### 11.1 /mcu/status

建议 ROS2 消息：

```text
mcu_comm_bridge/msg/McuStatus.msg
```

至少包含：

```text
std_msgs/Header header
uint32 mcu_stamp_ms
uint8 app_state
uint8 manual_mode
uint8 ready_flags
uint8 online_flags
uint8 fault_source
uint8 fault_level
int16 fault_code
bool auto_start_latched
```

推荐话题：

```text
/mcu/status
```

推荐 QoS：

```text
Reliable
KeepLast(1)
TransientLocal
```

目的：后启动的任务管理节点可以立即获得最近一次 MCU 状态真值

### 11.2 Pi 端锁存跟踪规则

Pi 必须跟踪 `auto_start_latched` 和 `app_state`：

| 前值 | 新值 | app_state | Pi 行为 |
|---:|---:|---|---|
| 0 | 0 | 任意 | 不重复 RESET |
| 0 | 1 | `AutoPi` | 产生一次 START |
| 0 | 1 | 非 `AutoPi` | 标记 pending，等待 `AutoPi` |
| 1 | 1 | `AutoPi` | 不重复 START |
| 1 | 1 | 非 `AutoPi` | 保持锁存，不启动新任务 |
| 1 | 0 | 任意 | 清理自动任务上下文，产生一次 RESET |

首次收到状态：

1. `flag=0`：建立基线，清理一次本地自动任务上下文，但不持续发布 RESET
2. `flag=1 && state=AutoPi`：产生一次 START，支持 Pi 晚启动恢复
3. `flag=1 && state!=AutoPi`：保持 pending，不启动任务

START 有效条件：

```text
auto_start_latched == 1
app_state == AUTO_PI
本轮 START 尚未消费
```

### 11.3 /mcu/auto_task_event

建议 ROS2 消息：

```text
mcu_comm_bridge/msg/AutoTaskEvent.msg
```

建议内容：

```text
std_msgs/Header header

uint8 EVENT_START=1
uint8 EVENT_RESET=2

uint8 event
uint32 mcu_stamp_ms
uint8 app_state
bool auto_start_latched
```

推荐话题：

```text
/mcu/auto_task_event
```

推荐 QoS：

```text
Reliable
KeepLast(10)
Volatile
```

不能为一次性事件使用 `TransientLocal`，避免新订阅者把旧 START 当成新任务

职责区分：

```text
/mcu/status：持续状态真值
/mcu/auto_task_event：START / RESET 边沿事件
```

### 11.4 Pi RESET 时清理范围

检测到 `1 -> 0` 后，Pi 应统一调用自动任务上下文复位逻辑，清理：

1. 本轮 START 已触发和已消费标志
2. mission active/done/failed 状态
3. pending mission result
4. 待重发的旧自动底盘控制
5. 待重发的旧机械臂目标
6. 待重发的旧 yaw action
7. 上一轮自动任务命令序号和业务去重状态
8. 与本轮任务相关的 timer、retry、action client 和任务管理上下文

不得清理：

1. 串口连接
2. 二进制流解析器
3. 帧统计和基础诊断
4. IMU/ODOM/ARM_STATE 最近数据
5. `MCU_STATUS` 最近状态
6. ROS2 publisher/subscriber 本身
7. Pi 心跳发送器

### 11.5 日志要求

MCU 周期心跳日志至少包含：

```text
state
manual_mode
remote_online
pc_online
pi_online
auto_start_latched
has_fault
fault_source
fault_level
fault_code
```

示例：

```text
Heartbeat state=AutoPi manual=ManualChassisPcArm remote=1 pc=0 pi=1 auto_start=1 fault=0 src=0 level=0 code=0
```

Pi 只在变化时打印：

```text
MCU state changed: Idle -> AutoPi, auto_start=1
MCU auto_start_latched changed: 0 -> 1
MCU auto task START detected: state=AutoPi auto_start=1
MCU auto_start_latched changed: 1 -> 0
MCU auto task RESET detected: local task context cleared
```

禁止按 `MCU_STATUS` 的 10 Hz 周期重复打印相同变化日志

---

## 12. 高频、一次性和锁存数据分类

### 12.1 高频连续数据

包括：

1. `PC_MASTER_JOINTS`
2. `PI_CONTROL.chassis`
3. `MCU_IMU`
4. `MCU_ODOM`
5. `MCU_ARM_STATE`

消费方式：

```text
get + fresh timeout 或周期覆盖
```

### 12.2 一次性动作

包括：

1. `PI_ARM_ACTION`
2. `PI_YAW_ACTION`
3. `PI_MISSION_EVENT`
4. `PI_ESTOP`
5. `PI_CONTROL.arm` 的新 `command_seq`

消费方式：

```text
take/consume
```

同一缓存结果不得在主循环内重复执行

### 12.3 跨状态锁存量

包括：

```text
MCU_STATUS.auto_start_latched
```

特征：

1. 不是瞬时事件
2. 不是 fresh timeout 控制量
3. 跨越 `AutoPi / Finished / Fault / Manual` 持续保持
4. 只有明确的 clear/reset 手势可以清零
5. Pi 通过边沿生成自己的 START/RESET 事件

---

## 13. ACK 与重发

当前 ACK 重点覆盖 `MCU_START_SENSOR_EVENT`：

1. 发送时设置 `FLAGS.NEED_ACK`
2. 首次发送分配固定 `SEQ`
3. 未收到 ACK 时每 `100 ms` 重发
4. 重发必须保持相同 `SEQ`
5. 收到匹配的 `ack_msg_id + ack_seq` 后清 pending
6. ACK 超时只统计和限频告警，不进入 `Fault`
7. ACK 不用于高频控制帧
8. `auto_start_latched` 依靠周期 `MCU_STATUS` 同步，不使用 ACK

---

## 14. 错误处理策略

以下情况只丢帧、统计和限频告警：

1. CRC 错误
2. 长度错误
3. 未知 `MSG_ID`
4. 协议版本错误
5. ACK 不匹配
6. 非法 action 或 arm_mode
7. 非法 `auto_start_latched` 原始值
8. 非有限机械臂目标
9. IK 无解
10. 目标越界

以下情况可能进入 `Fault`：

1. 底盘真实执行失败
2. 机械臂真实执行失败
3. 关键依赖未就绪但当前状态必须使用
4. `AutoPi` 下 Pi 离线
5. Pi 上报 `MISSION FAIL`

特别约束：

1. 非 `AutoPi` 状态下 Pi 离线不影响手动控制
2. 非 `ManualChassisPcArm` 状态下 PC 离线不影响其他模式
3. 启动条件不足时只拒绝本次启动，不应直接进入 `Fault`
4. recoverable Fault 可由 clear/reset 手势清除
5. fatal Fault 和 EStop 不得被普通 clear/reset 解除

---

## 15. 推荐频率和超时

| 消息 / 项目 | 推荐值 / 当前值 |
|---|---|
| `PC_HEARTBEAT` | 1 Hz |
| `PC_MASTER_JOINTS` | 30~100 Hz，当前默认 50 Hz |
| `PI_HEARTBEAT` | 1 Hz |
| `PI_CONTROL` | 20~50 Hz，当前默认 50 Hz |
| `MCU_STATUS` | 10 Hz |
| `MCU_IMU` | 100 Hz |
| `MCU_ODOM` | 50 Hz |
| `MCU_ARM_STATE` | 50 Hz |
| `MCU_START_SENSOR_EVENT` retry | 100 ms |
| Pi 在线超时 | 3000 ms |
| Pi 底盘控制 fresh timeout | 200 ms |
| Pi 机械臂控制 fresh timeout | 200 ms |
| Pi yaw 控制 fresh timeout | 200 ms |
| 遥控器在线超时 | 100 ms |

发送要求：

1. 发送函数不得长时间阻塞
2. ACK 缺失不得阻塞主循环
3. 500 Hz 主循环不得无节制发送大帧
4. 高频周期帧应错峰发送
5. 心跳频率必须显著高于在线超时所需最低频率

当前 MCU 发送槽位设计：

```text
2 ms 基础槽位
50 个槽位构成 100 ms 周期
IMU:       10 次 / 100 ms = 100 Hz
ODOM:       5 次 / 100 ms = 50 Hz
ARM_STATE:  5 次 / 100 ms = 50 Hz
STATUS:     1 次 / 100 ms = 10 Hz
```

---

## 16. 实现边界

1. `remote.c` 只负责遥控器在线状态、通道解析和边沿事件生成
2. `remote.c` 不得直接修改 `auto_start_latched`
3. `remote.c` 不得调用状态机
4. `app_runtime` 负责锁存标志、状态权限和启动条件检查
5. `app_status` 负责组装状态快照
6. `pi_comms` 只负责将状态快照打包为 `MCU_STATUS`
7. `pi_comms_clear_controls()` 只能清普通控制和普通一次性动作，不得清 pending EStop
8. Pi bridge 只负责协议桥接和边沿发布，不直接启动 Nav2
9. 上层任务管理器订阅 `/mcu/auto_task_event`，执行任务启动和取消
10. UART/HAL 绑定由 assemble 层完成
11. 不使用动态内存实现 MCU 协议状态

---

## 17. 兼容性与部署要求

本修订将 `MCU_STATUS` offset 12 从 reserved 改为 `auto_start_latched`：

1. payload 仍为 16 字节
2. 旧 Pi 解析器会忽略该字节，不会发生帧长度错误
3. 新 Pi 配合旧 MCU 时会一直读到 0，无法检测有效 START
4. 旧 Pi 配合新 MCU 时不会发布 START/RESET 边沿
5. MCU 和 Pi 的本次功能应同步部署和验收
6. 如果未来需要强制拒绝旧端，可升级 `VER`；当前阶段保持 `VER=0x01` 以减少线协议破坏

---

## 18. 验收场景

### 18.1 初始状态

```text
MCU state=Idle
auto_start_latched=0
Pi 建立 0 基线
```

### 18.2 正常启动

```text
遥控器先处于非自动条件
再进入自动条件
Pi online，chassis/odom ready
```

预期：

```text
MCU: Idle -> AutoPi
MCU: auto_start_latched 0 -> 1
Pi:  发布一次 START
```

### 18.3 自动条件持续保持

预期：

```text
不重复启动
不重复清理 Pi 控制缓存
不重复发布 START
```

### 18.4 释放后重新进入自动条件，但未 clear/reset

预期：

```text
auto_start_latched 仍为 1
拒绝新任务
```

### 18.5 任务完成

```text
Pi -> MCU: MISSION DONE
```

预期：

```text
MCU: AutoPi -> Finished
auto_start_latched 仍为 1
Pi 不重复 START
```

### 18.6 任务失败

```text
Pi -> MCU: MISSION FAIL
```

预期：

```text
MCU 进入 recoverable Fault
auto_start_latched 仍为 1
```

### 18.7 clear/reset

```text
SWC 高，VRA 低，VRB 低
```

预期：

```text
MCU: auto_start_latched 1 -> 0
MCU 清自动任务上下文
Pi: 清本地任务上下文
Pi: 发布一次 RESET
```

### 18.8 clear/reset 持续保持

预期：

```text
只处理一次
不重复 RESET
不刷日志
```

### 18.9 第二轮任务

```text
clear/reset 完成
离开 clear/reset 手势
重新形成自动启动边沿
```

预期：

```text
MCU: Idle -> AutoPi
MCU: auto_start_latched 0 -> 1
Pi: 再发布一次 START
```

### 18.10 AutoPi 中 clear/reset

预期：

```text
停止执行机构
清普通 Pi 控制
AutoPi -> Idle
auto_start_latched=0
Pi 发布 RESET
```

### 18.11 EStop 中 clear/reset

预期：

```text
auto_start_latched=0
清普通自动任务上下文
继续保持 EStop
```

### 18.12 Pi 晚启动

MCU 已经：

```text
app_state=AutoPi
auto_start_latched=1
```

Pi bridge 启动后首次收到状态，预期产生一次 START

---

## 19. 后续扩展规则

1. 新增消息优先复用现有统一帧格式
2. 需要 ACK 的一次性线消息统一使用 `SEQ + NEED_ACK + ACK`
3. 不在 PC、Pi、MCU 三端分别实现不同 CRC 变体
4. 新 payload 必须补 offset 表、类型、单位和合法值
5. 新状态字段优先从 reserved 区扩展；不足时再增加新消息或升级协议版本
6. 未来增加光电传感器时，可复用统一的 MCU 启动请求仲裁，但不得绕过 `auto_start_latched`
7. 不同启动源可以通过 `MCU_START_SENSOR_EVENT` 告知来源，但任务启动真值仍以 `MCU_STATUS.app_state + auto_start_latched` 为准
8. Pi 上层任务管理器必须以一次性 START/RESET 边沿驱动任务，不得按 10 Hz 状态帧反复启动或清理

---

# 19 ASRPRO TWEN51 与 Pi 通信协议

## 19.1 协议边界

ASRPRO 不使用 MCU 二进制帧；它通过独立 USB 串口与树莓派通信；默认设备为 `/dev/atlas_asrpro`；默认波特率为 `115200`

ASRPRO 只提供

```text
离线语音识别 intent
固定 phrase_id 离线播报
设备握手
心跳
ACK；NACK；事件重试和去重
```

ASRPRO 不直接向 MCU 发送任何命令

## 19.2 帧格式

```text
@DIRECTION,VERSION,SEQUENCE,COMMAND,ARG1,ARG2*HH\r\n
```

`HH` 为载荷 UTF-8 字节 XOR；当前版本为 `1`

## 19.3 命令

```text
P2A HELLO firmware_version boot_id
A2P HELLO_ACK boot_id
A2P LISTEN 0|1
A2P SPEAK phrase_id
P2A ACK command
P2A NACK command reason
P2A EVENT ASR intent
P2A EVENT SPEAK_DONE phrase_id
A2P EVENT_ACK event_type
A2P PING timestamp
P2A PONG timestamp
```

## 19.4 全自主启动时序

```text
ASRPRO 上电并周期发送 HELLO
→ Pi atlas_asrpro_bridge 返回 HELLO_ACK
→ Pi 发送 LISTEN,1
→ ASRPRO 返回 ACK
→ MCU AutoPi 手势建立 auto_start_latched
→ 状态机请求 SPEAK transition_complete
→ ASRPRO 播报并发送 SPEAK_DONE
→ 状态机请求 SPEAK voice_prompt
→ ASRPRO 播报并发送 SPEAK_DONE
→ 操作员说 Atlas 启动
→ ASRPRO 发送 EVENT ASR atlas_start
→ 状态机请求 SPEAK autonomous_start
→ 播报完成后进入全自主运输
```

## 19.5 详细适配

完整帧示例；phrase_id 表；intent 表；固件伪代码；重发和去重要求见

```text
docs/ASRPRO_TWEN51适配与烧录说明.md
```

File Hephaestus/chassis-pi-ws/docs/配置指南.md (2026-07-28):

# Atlas 全自主运输区配置指南

## 1 适用范围

本指南只配置智械争锋全自主运输区；遥操作区；PC 端和 MCU 固件不在本次配置范围内

完整任务由以下入口统一启动

```bash
ros2 launch robot_startup robot_autonomous_transport.launch.py
```

统一配置文件位于

```text
chassis-pi-ws/src/app/atlas_autonomous_transport_manager/config/autonomous_transport.yaml
```

该 YAML 同时管理启动顺序；导航后端；视觉模型路径；相机设备；ASRPRO；任务时间；园区映射策略；地图点和机械臂动作名称

## 2 系统依赖

推荐环境

```text
Ubuntu 22.04
ROS 2 Humble
Python 3.10
OpenCV
ONNX Runtime
pyserial
Nav2
Cartographer ROS
```

安装常用依赖

```bash
sudo apt update
sudo apt install -y \
  python3-colcon-common-extensions \
  python3-rosdep \
  python3-yaml \
  python3-serial \
  python3-opencv \
  ros-humble-navigation2 \
  ros-humble-nav2-bringup \
  ros-humble-cartographer \
  ros-humble-cartographer-ros \
  ros-humble-tf2-tools
```

ONNX Runtime 按树莓派架构安装；安装完成后先验证

```bash
python3 -c "import onnxruntime; print(onnxruntime.__version__)"
```

## 3 工作区编译

```bash
cd ~/Atlas/chassis-pi-ws
source /opt/ros/humble/setup.bash
rosdep install --from-paths src --ignore-src -r -y
colcon build --symlink-install
source install/setup.bash
```

验证关键功能包

```bash
ros2 pkg prefix atlas_autonomous_transport_manager
ros2 pkg prefix atlas_asrpro_bridge
ros2 pkg prefix vison_topic
ros2 pkg prefix atlas_racom_vision_backend
ros2 pkg prefix robot_startup
```

## 4 串口和相机固定名称

正式比赛前固定以下设备名

```text
/dev/atlas_mcu
/dev/atlas_asrpro
/dev/atlas_lidar
/dev/atlas_camera
```

完整操作见 `docs/串口固定绑定教程.md`

配置完成后检查

```bash
ls -l /dev/atlas_mcu /dev/atlas_asrpro /dev/atlas_lidar /dev/atlas_camera
udevadm info -q property -n /dev/atlas_mcu
udevadm info -q property -n /dev/atlas_asrpro
```

Pi 端 MCU 桥默认读取

```text
src/mcu_comm_bridge/config/mcu_comm_bridge.yaml
port: /dev/atlas_mcu
```

ASRPRO 桥默认读取

```text
src/asrpro/atlas_asrpro_bridge/config/asrpro.yaml
port: /dev/atlas_asrpro
baudrate: 115200
```

## 5 统一 YAML 的 system 段

### 5.1 启动延时

```yaml
system:
  startup:
    asrpro_delay_s: 0.0
    mcu_delay_s: 0.0
    sensor_delay_s: 1.0
    navigation_delay_s: 2.0
    vision_delay_s: 3.0
    manipulation_delay_s: 4.0
    manager_delay_s: 6.0
```

启动延时只负责组织节点顺序；状态机仍会检查 MCU 状态；ASRPRO 状态和所有依赖服务；因此不要通过缩短延时绕过预检

### 5.2 路径解析规则

`system.paths` 中留空表示使用功能包安装目录中的默认文件；填写绝对路径时直接使用；填写相对路径时按统一 YAML 所在目录解析

示例

```yaml
system:
  paths:
    vision_model_path: "/home/wheeltec/models/best.onnx"
    vision_labels_path: "/home/wheeltec/models/labels.txt"
    map_yaml: "/home/wheeltec/maps/competition.yaml"
    cartographer_pbstream: "/home/wheeltec/maps/competition.pbstream"
```

路径包含空格时必须使用引号

## 6 最新视觉模型配置

最新 `vision_system.zip` 已放入

```text
chassis-pi-ws/src/vision_system
```

默认模型位于

```text
src/vision_system/rui_vison/vison_topic/resource/best.onnx
```

编译后安装到

```text
install/vison_topic/share/vison_topic/resource/best.onnx
```

统一 YAML 中的配置

```yaml
system:
  paths:
    vision_runtime_config: ""
    vision_model_path: ""
    vision_labels_path: ""
  vision:
    camera: "/dev/atlas_camera"
    confidence_threshold: 0.55
    process_every_n: 2
    rate_hz: 10.0
```

`vision_model_path` 留空时使用内置最新模型；填写后使用外部模型；若填写路径不存在；视觉节点会明确报错并退出；launch 会按配置重启节点

模型参数优先级从高到低为

```text
统一 YAML 中 system.paths 和 system.vision
→ vision_runtime.yaml
→ detect_and_send.py 默认值
```

类别文件每行一个名称；当前比赛适配器至少需要识别齿轮和 T 型螺栓对应类别；默认别名位于

```text
src/vision_system/racom_vision/atlas_racom_vision_backend/config/sorting_rule.yaml
```

视觉配置和标定见 `docs/视觉模型配置与标定.md`

## 7 ASRPRO TWEN51 配置

ASRPRO 固件应包含以下稳定 intent

```text
atlas_start
```

建议离线识别词

```text
Atlas 启动
阿特拉斯启动
开始全自主运输
```

ASRPRO 固件应包含以下 phrase_id

```text
transition_complete
voice_prompt
autonomous_start
delivery_complete
task_complete
task_skipped
```

统一 YAML 配置

```yaml
autonomous_transport:
  voice:
    start_required: true
    start_timeout_s: 0.0
    fallback_enabled: false
    asrpro_status_timeout_s: 2.0
    speech_timeout_s: 8.0
    speech_retry_count: 2
    accepted_intents: ["atlas_start"]
```

`start_timeout_s: 0.0` 表示一直等待语音触发；等待期间底盘制动；机械臂不动作；恢复手势和遥控接管仍保持有效

ASRPRO 详细适配见 `docs/ASRPRO_TWEN51适配与烧录说明.md`

## 8 导航配置

全自主区四个停车点必须使用 `map` 绝对坐标

```yaml
autonomous_transport:
  waypoints:
    sorting_area:
      x_m: 0.0
      y_m: 0.0
      yaw_rad: 0.0
    dispatch_area:
      x_m: 0.0
      y_m: 0.0
      yaw_rad: 0.0
    park_1:
      x_m: 0.0
      y_m: 0.0
      yaw_rad: 0.0
    park_2:
      x_m: 0.0
      y_m: 0.0
      yaw_rad: 0.0
```

标定方法

1. 启动定位和 Nav2；不要启动任务状态机
2. 手动把机器人停到智能分拣识别位；记录 `map -> base_footprint`
3. 记录待派送区抓取位；园区 1 投放位；园区 2 投放位
4. 每个停车点至少重复到达五次；检查机械臂可达性和底盘边界余量
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

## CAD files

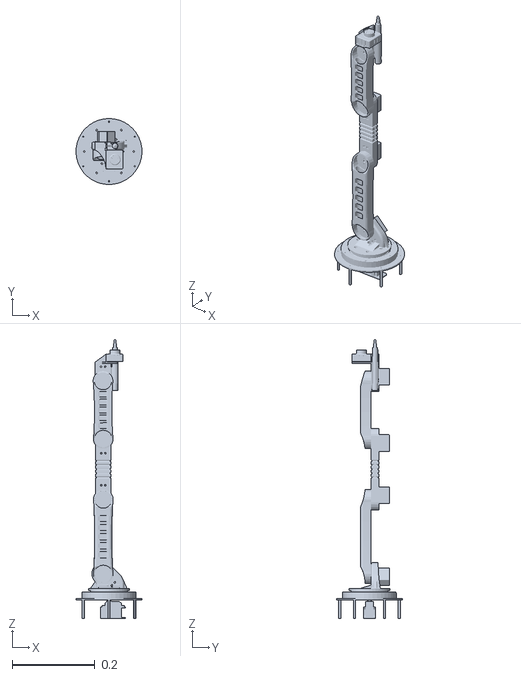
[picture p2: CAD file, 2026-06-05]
Atlas/chassis_control_code/arm_description/meshes/base_link.STL
0.16 x 0.16 x 0.676

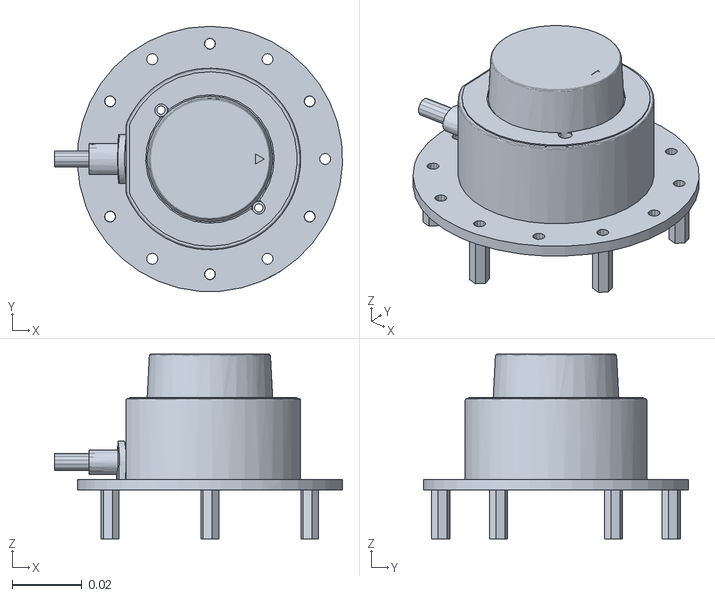
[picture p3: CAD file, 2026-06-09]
Hephaestus/chassis-pi-ws/src/nav_system/robot_description/meshes/laser_frame.STL
0.0825 x 0.076 x 0.053

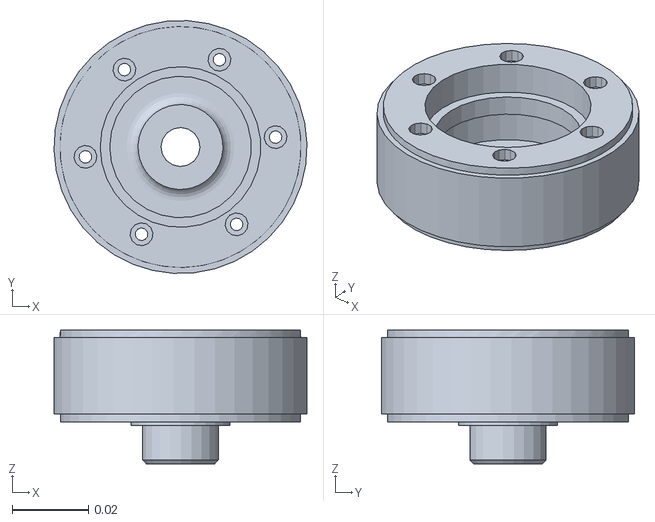
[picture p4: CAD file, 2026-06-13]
Hephaestus/chassis_control_code/arm_description/meshes/RRd_Link.STL
0.0662 x 0.0661 x 0.035

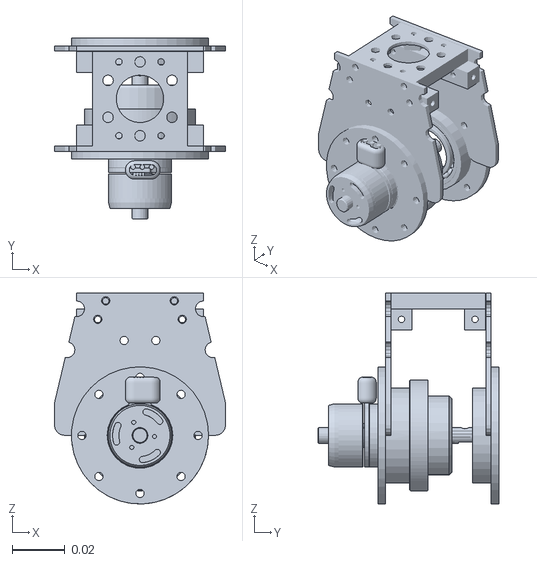
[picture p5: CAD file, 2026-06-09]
Hephaestus/chassis-pi-ws/src/nav_system/robot_description/meshes/RFs_Link.STL
0.065 x 0.0687 x 0.08

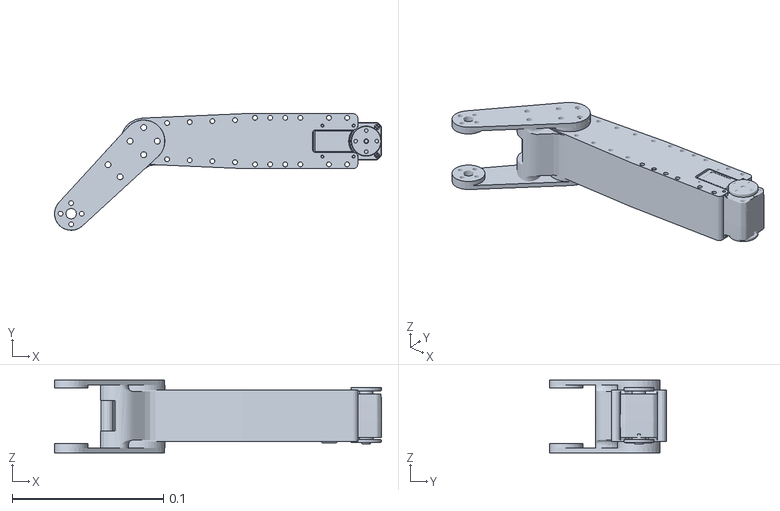
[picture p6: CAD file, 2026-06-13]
Hephaestus/chassis_control_code/arm_description/meshes/arm2_Link.STL
0.216 x 0.0771 x 0.048

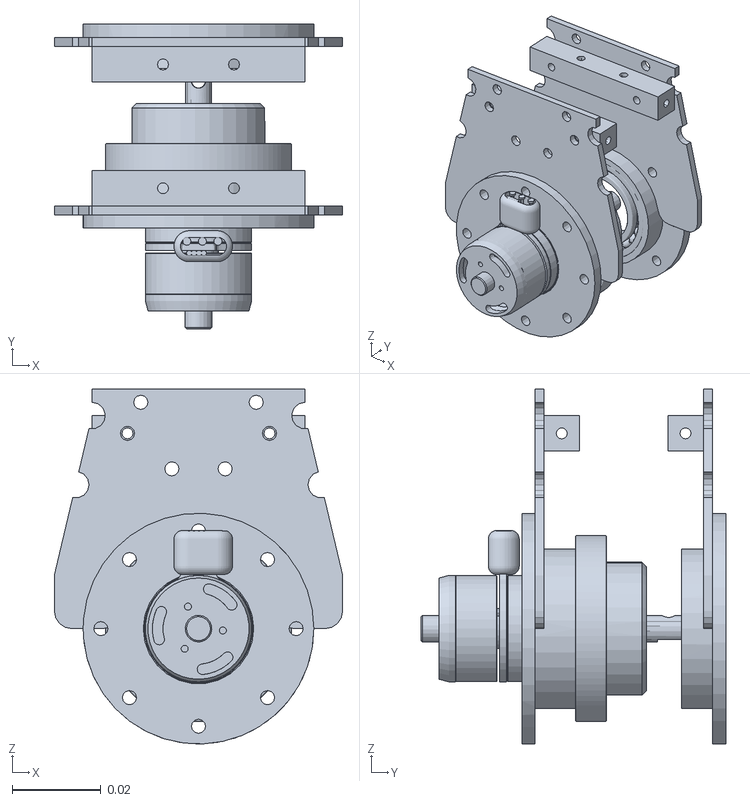
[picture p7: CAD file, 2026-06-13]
Hephaestus/chassis_control_code/arm_description/meshes/RRs_Link.STL
0.065 x 0.0687 x 0.08

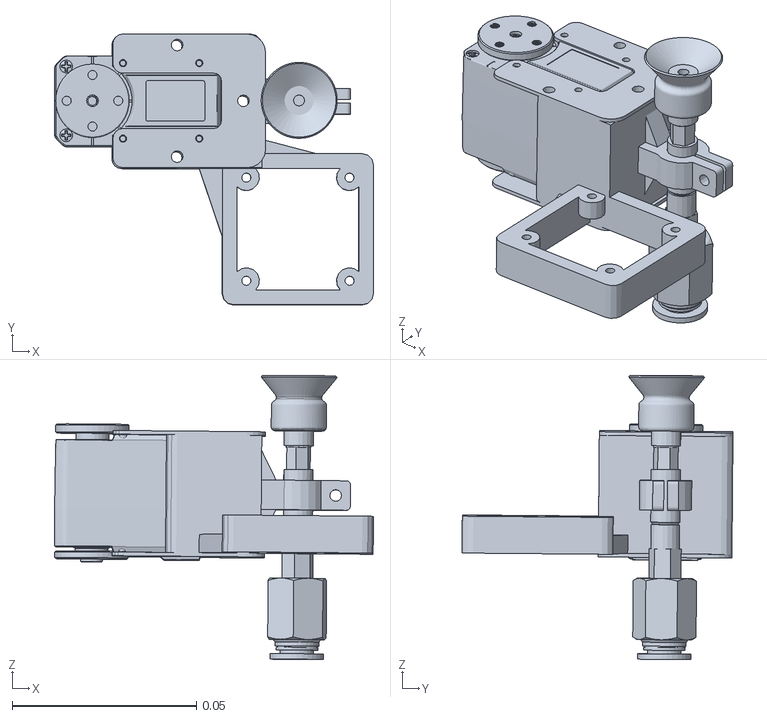
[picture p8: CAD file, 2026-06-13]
Hephaestus/chassis_control_code/arm_description/meshes/arm4_Link.STL
0.0866 x 0.0736 x 0.0772

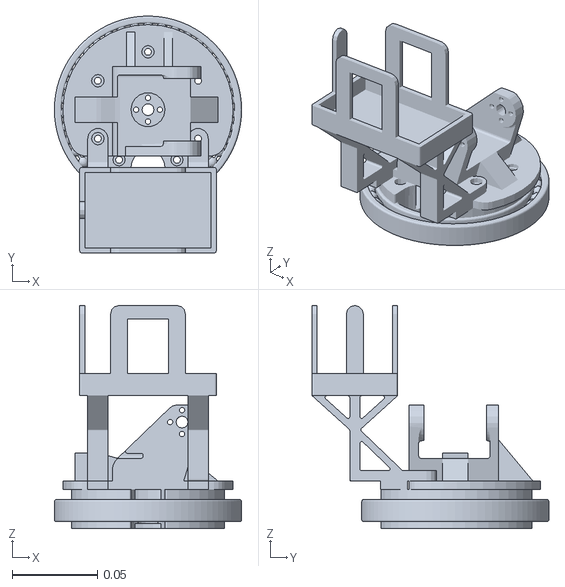
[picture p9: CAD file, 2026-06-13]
Hephaestus/chassis_control_code/arm_description/meshes/arm0_Link.STL
0.11 x 0.139 x 0.131

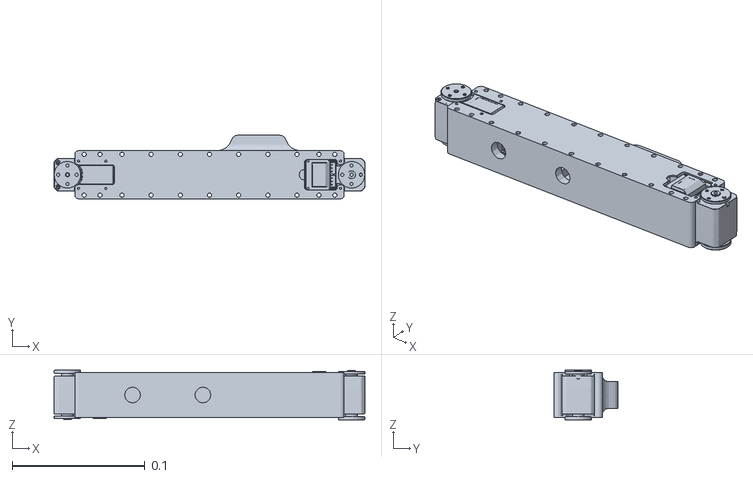
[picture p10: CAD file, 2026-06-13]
Hephaestus/chassis_control_code/arm_description/meshes/arm1_Link.STL
0.235 x 0.048 x 0.0376

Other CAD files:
Hephaestus/chassis_control_code/arm_description/meshes/RFd_Link.STL
Hephaestus/chassis-pi-ws/src/nav_system/robot_description/meshes/LRd_Link.STL
Hephaestus/chassis-pi-ws/src/nav_system/robot_description/meshes/LFs_Link.STL
Hephaestus/chassis-pi-ws/src/nav_system/robot_description/meshes/LFd_Link.STL
Hephaestus/chassis-pi-ws/src/nav_system/robot_description/meshes/LRs_Link.STL
Hephaestus/chassis-pi-ws/src/nav_system/robot_description/meshes/RRd_Link.STL
Hephaestus/chassis_control_code/arm_description/meshes/LFs_Link.STL
Hephaestus/chassis-pi-ws/src/nav_system/robot_description/meshes/RRs_Link.STL
Hephaestus/chassis-pi-ws/src/nav_system/robot_description/meshes/RFd_Link.STL
Hephaestus/chassis_control_code/arm_description/meshes/LFd_Link.STL
Hephaestus/chassis_control_code/arm_description/meshes/LRd_Link.STL
Hephaestus/chassis_control_code/arm_description/meshes/LRs_Link.STL
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

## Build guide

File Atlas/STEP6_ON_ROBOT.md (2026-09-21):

# Step 6 集中真机验收

本包基于用户提供的 Step 1/2 完成包续作，包含 Step 3—5 源码和主机回归

当前尚未通过完整 MCU 编译、ROS 2 构建及真机验收，不能标记 Step 6 完成

## 1 编译和部署

MCU 与 Pi 必须配套更新，新 pitch/yaw 表示工具 z 轴方向，不能与旧 RPY 固件混用

先保存现场当前版本，在新目录解压本包，核对本地未提交修改后再替换对应源码

MCU 使用原有 EIDE 工程打开 `chassis_control_code/robot.code-workspace`，保持现有 GCC Cortex-M7 配置，执行完整 Rebuild，再烧录本次生成的固件

本包未包含旧 `build/Debug/robot.hex` 或 `robot.elf`，避免误烧旧版本

Pi 在新的 ROS 2 Humble 终端执行

```bash
cd Atlas/chassis-pi-ws
source /opt/ros/humble/setup.bash
colcon build --symlink-install --packages-up-to atlas_competition_bringup
source install/setup.bash
ros2 interface show mcu_comm_bridge/msg/ArmCommandResult
ros2 interface show vison_topic_interfaces/msg/PickTarget
ros2 interface show vison_topic_interfaces/msg/PickResult
```

确认 `PickTarget` 包含 `request_id` 和 `cancel`，`PickResult` 包含目标 XYZ 和方向角

所有使用 `vison_topic_interfaces` 的节点都需重新构建并重启，新增字段不保证与旧生成消息兼容

## 2 启动并记录

先用完整软件栈但关闭任务自动调度、导航和雷达，机械臂模式按原有操作进入 AutoPi

```bash
ros2 launch atlas_competition_bringup competition_stack.launch.py \
  enable_mission:=false enable_navigation:=false enable_lidar:=false
```

另开终端并加载同一工作空间

```bash
ros2 param get /atlas_competition_manipulation_backend view_scan.enabled
ros2 topic echo /mcu/arm_command_result
```

`view_scan.enabled` 应为 true，实际查询结果仍需现场确认

录包覆盖本次整个验收 session

```bash
ros2 bag record -o atlas_step6_acceptance \
  /arm/pose /arm/joint_states /mcu/arm_command_result \
  /pick_target /pick_result /vision_pose_ready /atlas/manipulation/status
```

## 3 逐点矩阵

`validation/step3_step5/step6_targets.yaml` 已列出 8 个 pickup 和 16 个 placement 目标，以及对应出发关节角

每个 pickup 先回该项 `seed_joints_rad`，再测试目标 XYZ，方向保持该观察位工具轴

每个 placement 先回相应 park prepare，再依次到目标上方 0.06 m、目标高度、目标上方 0.06 m，三段 pitch 均为 −π/2、yaw 为 0

这些是静态生成的测试目标，不是实际抓取定位结果，现场真实抓取仍由检测帧同步位姿计算

逐条调用下列服务，将花括号内数值替换为矩阵中的对应值，先等待上一条到位再发下一条

```bash
ros2 service call /mcu/set_arm_joints mcu_comm_bridge/srv/SetArmJoints \
  '{joints_rad: [q0, q1, q2, q3, q4], speed_rad_s: 0.3, suction_valid: false, suction_enable: false}'

ros2 service call /mcu/set_arm_pose mcu_comm_bridge/srv/SetArmPose \
  '{x_m: x, y_m: y, z_m: z, pitch_rad: pitch, yaw_rad: yaw, speed_rad_s: 0.3, suction_valid: false, suction_enable: false}'
```

上面是模板，`q0`、`x` 等必须替换为数值后执行

每条记录 service 返回的 `command_seq`、同 seq 的 MCU `result/arm_status`、到位 XYZ、工具轴和位置/姿态残差

`result=0` 表示 MCU 真正接受，不表示已经到位；必须结合后续新鲜反馈判断

姿态残差只比较工具 z 轴夹角，要求小于 3°，不约束末端自由自旋

反馈四元数为 `(qx,qy,qz,qw)` 时先归一化，再计算工具轴

```text
d_actual = [2(qx*qz+qw*qy), 2(qy*qz-qw*qx), 1-2(qx²+qy²)]
d_target = [cos(pitch)cos(yaw), cos(pitch)sin(yaw), sin(pitch)]
axis_error = acos(clamp(dot(d_actual,d_target),-1,1))
```

不得出现工具轴 180° 翻转，观察位 XYZ 正确但轴向错误时 `/vision_pose_ready` 必须为 false

## 4 失败与完整流程

在同一 session 中覆盖以下情况

- 不可达姿态返回 NO_SOLUTION，而不是只有服务 queued 成功
- 无检测、过期帧、位姿不同步、workspace 拒绝能在 `/pick_result` 看到明确 reason
- 观察位切换后不复用旧 best frame
- 抓取失败进入既有 deferred retry，而不是因错误 slot 进入全局 Recovery
- 取消预备抓取后不再自动发送后续 contact

`cancel` 仅取消未发送的后续抓取阶段，不是物理急停，已被 MCU 接受的动作仍需使用原有急停/模式控制处理

完成逐点验证后结束前一个 launch，启动原有全自主测试入口

```bash
ros2 launch atlas_competition_bringup auto_zone_test.launch.py
```

按照原有启动流程执行一次完整抓放链

观察 → 检测 → 抓取 → 吸附 1.5 s → 姿态保持抬升 → 搬运 → park prepare → 水平放置 → 释放 → 下一货物或 retry

验收前保持 `manual_offset_x_m=-0.055`、plane1/plane2 和各 slot 层高原值，本轮不凭现象重新标定来补偿运动学

请保留构建日志、录包、失败点名称与对应 command_seq，供核对结果

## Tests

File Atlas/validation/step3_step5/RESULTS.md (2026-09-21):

# Step 3—5 交付与验证

## 当前状态

| 项目 | 结果 |
|---|---|
| Step 1/2 已有 IK 修复 | 保留，主机回归通过 |
| Step 3 Pi 全程工具轴保持 | 已实现并通过专项测试 |
| Step 4 MCU → Pi → Pick 真实结果 | 已实现，主机协议与回调测试通过 |
| Step 5 视觉有效性 | 已实现，专项测试通过 |
| Step 5 deferred retry | 本基线逻辑已正确，新增回归通过，未放宽 scheduler 校验 |
| Step 6 集中真机验收 | NOT RUN，需要现场执行 |

## 主要改动

- handeye 从检测帧对应变换提取工具 z 轴，停止依赖旧 initial magic RPY
- lift、view scan、place 三段全部使用 SetArmPose，place 工具轴向下
- MCU 新增 0x28 结果帧和有界序号结果缓存，Pi 发布 ArmCommandResult
- ACCEPTED 来自实际 ArmStatus，分别处理无解、参数错误、运动学失败、舵机失败、超时和未知结果
- PickResult 按 request_id 关联视觉拒绝或 MCU 结果，并携带 contact 目标
- 上层先等真实接受，再等新鲜、不同时间戳的 XYZ 和工具轴到位反馈
- 视觉门禁要求 TCP 在 0.2 s 窗口位移小于 1 mm、工具轴误差小于 5°，并检查反馈新鲜度
- 切换观察位、移动、过期门禁和检测重启清理旧帧
- 补齐取消抓取后禁止继续下探、取消旧任务未退出时拒绝新任务的回归

## 实际验证

运行 `run_host_regressions.sh`，依赖 Python pytest、numpy、PyYAML 及主机 cc/g++

| 验证 | 实际结果 |
|---|---|
| manipulation、handeye、detector 专项 Python 测试 | 59 passed |
| 通用 SO(3)、5D/6D、A/B pickup 和 park IK 主机回归 | ALL TESTS PASSED |
| MCU ArmStatus 映射、重复帧、超时、取消、UART 重试 | PASS |
| MCU 未初始化与非 AutoPi 模式拒绝 | PASS |
| Pi 结果帧校验和线协议往返 | PASS |
| CompetitionModel 主机断言测试 | 11 tests, 0 failed |

C++ 调度测试通过包内简易断言适配器执行现有 gtest 风格测试，不等同于 ROS/ament 构建

MCU 协议测试使用模拟 UART/arm 服务，不能代替物理舵机和真实 IK 拒绝验收

## 审查与执行判断

独立代码审查提出三项 Important 问题，均已修复并有针对性回归

1. handeye 在门禁失效后保留旧最终帧 → 清理检测缓存、限制当前 readiness 时间区间
2. 取消 approach 后仍可能发送 contact → 按 request_id 取消后续阶段
3. backend 把旧反馈接收时间当新采样 → 检查消息源时间戳、新鲜度及重复样本

执行判断

- 使用上传 Step 1/2 包作为续作基线，未新建分支、commit 或 push
- PickResult 增加最终目标，避免把 MCU 接受误当成实际到位；部署须重新生成消息
- review 中 scheduler lookup 改变游标的前提现已不成立，保留既有合法 slot 校验；如果现场使用其他版本，须重新核对该版本
- 取消只阻止后续自动阶段，不改变已接受动作的物理停止策略

## 未验证边界

当前环境无 arm-none-eabi-gcc、colcon/ROS 2，因此完整固件编译、消息生成、ROS 节点链接、安装后资源解析、实时参数、UART/DDS 联调和真机矩阵均未执行

结果缓存为最近 16 条 MCU 命令，跨 MCU 重启不保留；全部重传结果丢失时上层按超时处理

源码保留原标定与偏置，未引入 Pi 第二套 IK

完整逐文件清单见 `CHANGED_FILES.txt`，现场操作见 `../../STEP6_ON_ROBOT.md`

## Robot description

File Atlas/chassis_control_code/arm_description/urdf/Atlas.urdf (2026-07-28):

<?xml version="1.0" encoding="utf-8"?>
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
<robot name="Atlas">
  <link name="base_link">
    <inertial>
      <origin xyz="-0.00882808429030593 -0.000340750676586599 0.0954179896198022" rpy="0 0 0" />
      <mass value="3.07994818862467" />
      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
    </inertial>
    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
  </link>
  <link name="rader_link">
    <inertial>
      <origin xyz="-3.28944182864182E-09 -2.79918769266761E-09 -0.034597418415799" rpy="0 0 0" />
      <mass value="0.0197577859576288" />
      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
    </inertial>
    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
  </link>
  <joint name="rader" type="fixed">
    <origin xyz="0 0 0.14485" rpy="0 0 0" />
    <parent link="base_link" />
    <child link="rader_link" />
    <axis xyz="0 0 0" />
  </joint>
  <link name="arm0_Link">
    <inertial>
      <origin xyz="4.03163124566112E-05 -0.00439694616931921 0.0181601133638054" rpy="0 0 0" />
      <mass value="0.497552971363212" />
      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
    </inertial>
    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
  </link>
  <joint name="arm0" type="continuous">
    <origin xyz="0.0299999999999805 0 0.2051" rpy="0 0 0" />
    <parent link="base_link" />
    <child link="arm0_Link" />
    <axis xyz="0 0 1" />
  </joint>
  <link name="arm1_Link">
    <inertial>
      <origin xyz="-0.111680854140069 0.00198264432767215 0.0167679006371422" rpy="0 0 0" />
      <mass value="0.146358923007007" />
      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
    </inertial>
    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
  </link>
  <joint name="arm1" type="revolute">
    <origin xyz="0.0276200491203067 0.0162679040568649 0.0604999999999996" rpy="1.5707963267949 0 0" />
    <parent link="arm0_Link" />
    <child link="arm1_Link" />
    <axis xyz="0 0 1" />
    <limit lower="-210" upper="0" effort="1" velocity="3" />
  </joint>
  <link name="arm2_Link">
    <inertial>
      <origin xyz="0.0938782231507684 0.0435998398556859 -0.00195286688151847" rpy="0 0 0" />
      <mass value="0.131033847495955" />
      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
    </inertial>
    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
  </link>
  <joint name="arm2" type="revolute">
    <origin xyz="-0.216724125670017 0 0.0192068569153542" rpy="0 0 0" />
    <parent link="arm1_Link" />
    <child link="arm2_Link" />
    <axis xyz="0 0 -1" />
    <limit lower="0" upper="270" effort="1" velocity="3" />
  </joint>
  <link name="arm3_Link">
    <inertial>
      <origin xyz="0.0203737284918072 -0.000593186652555089 -0.0194413021174199" rpy="0 0 0" />
      <mass value="0.0296160318942833" />
      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
    </inertial>
    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
  </link>
  <joint name="arm3" type="revolute">
    <origin xyz="0.19444619433893 0.0479984083069584 0.0171273498437832" rpy="0.00872697851440046 -0.00872598171315758 -7.61524215243458E-05" />
    <parent link="arm2_Link" />
    <child link="arm3_Link" />
    <axis xyz="-0.00872587097686341 -0.00872653549837514 -0.99992385047757" />
    <limit lower="0" upper="100" effort="1" velocity="3" />
  </joint>
  <link name="arm4_Link">
    <inertial>
      <origin xyz="0.0336761719446859 -0.00431914226118644 -0.0209655457993607" rpy="0 0 0" />
      <mass value="0.0527219852119685" />
      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
    </inertial>
    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
  </link>
  <joint name="arm4" type="revolute">
    <origin xyz="0.0442641199736169 -0.02032988697116 -0.0187765660482722" rpy="1.57039834747322 0.00838579561913363 -0.046675354326363" />
    <parent link="arm3_Link" />
    <child link="arm4_Link" />
    <axis xyz="-0.00872587097686579 -0.00872653549837382 -0.99992385047757" />
    <limit lower="-90" upper="90" effort="1" velocity="3" />
  </joint>
  <link name="LFs_Link">
    <inertial>
      <origin xyz="-3.43181858528108E-06 0.00109461595354032 -0.042474727115529" rpy="0 0 0" />
      <mass value="0.114715980836134" />
      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
    </inertial>
    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
  </link>
  <joint name="LFs" type="continuous">
    <origin xyz="0.132864923566373 0.132864941643627 0.0880999999999993" rpy="0 0 0" />
    <parent link="base_link" />
    <child link="LFs_Link" />
    <axis xyz="0 0 1" />
  </joint>
  <link name="LFd_Link">
    <inertial>
      <origin xyz="1.05702966834986E-06 -4.22896943676034E-05 -0.245388471723" rpy="0 0 0" />
      <mass value="0.055943603224693" />
      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
    </inertial>
    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
  </link>
  <joint name="LFd" type="continuous">
    <origin xyz="0 -0.246529876225633 -0.0549577103053627" rpy="1.5707963267949 0 0" />
    <parent link="LFs_Link" />
    <child link="LFd_Link" />
    <axis xyz="0 0 1" />
  </joint>
  <link name="LRs_Link">
    <inertial>
      <origin xyz="-3.42770024608363E-06 0.00109463116413308 -0.0424747271155208" rpy="0 0 0" />
      <mass value="0.114715980835617" />
      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
    </inertial>
    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
  </link>
  <joint name="LRs" type="continuous">
    <origin xyz="-0.132864949716031 0.132864926432914 0.0880999999999996" rpy="0 0 0" />
    <parent link="base_link" />
    <child link="LRs_Link" />
    <axis xyz="0 0 1" />
  </joint>
  <link name="LRd_Link">
    <inertial>
      <origin xyz="-0.265730935506289 -4.22896946470326E-05 -0.0180586188567917" rpy="0 0 0" />
      <mass value="0.055943603224693" />
      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
    </inertial>
    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
  </link>
  <joint name="LRd" type="continuous">
    <origin xyz="0.265730950640532 -0.0192000081487032 -0.0549577103053501" rpy="1.5707963267949 0 0" />
    <parent link="LRs_Link" />
    <child link="LRd_Link" />
    <axis xyz="0 0 -1" />
  </joint>
  <link name="RFs_Link">
    <inertial>
      <origin xyz="3.4428342126358E-06 -0.00109462301503871 -0.0424747271155201" rpy="0 0 0" />
      <mass value="0.114715980835538" />
      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
    </inertial>
    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
  </link>
  <joint name="RFs" type="continuous">
    <origin xyz="0.132864934581987 -0.132864934582007 0.0880999999999999" rpy="0 0 0" />
    <parent link="base_link" />
    <child link="RFs_Link" />
    <axis xyz="0 0 1" />
  </joint>
  <link name="RFd_Link">
    <inertial>
      <origin xyz="1.05702960509491E-06 -4.22896943118914E-05 0.0180586025589895" rpy="0 0 0" />
      <mass value="0.055943603224693" />
      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
    </inertial>
    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
  </link>
  <joint name="RFd" type="continuous">
    <origin xyz="0 0.0192000000000008 -0.0549577103053633" rpy="1.5707963267949 0 0" />
    <parent link="RFs_Link" />
    <child link="RFd_Link" />
    <axis xyz="0 0 1" />
  </joint>
  <link name="RRs_Link">
    <inertial>
      <origin xyz="3.56441174928501E-06 -0.0011332776704702 -0.0438441812611078" rpy="0 0 0" />
      <mass value="0.110803165091198" />
      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
    </inertial>
    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
  </link>
  <joint name="RRs" type="continuous">
    <origin xyz="-0.132864934582027 -0.132864934582008 0.0880999999999997" rpy="0 0 0" />
    <parent link="base_link" />
    <child link="RRs_Link" />
    <axis xyz="0 0 1" />
  </joint>
  <link name="RRd_Link">
    <inertial>
      <origin xyz="1.05702937794327E-06 -4.22896944309303E-05 0.0180586025589896" rpy="0 0 0" />
      <mass value="0.055943603224693" />
      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
    </inertial>
    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
  </link>
  <joint name="RRd" type="continuous">
    <origin xyz="0 0.0192000000000007 -0.0549577103053587" rpy="1.5707963267949 0 0" />
    <parent link="RRs_Link" />
    <child link="RRd_Link" />
    <axis xyz="0 0 1" />
  </joint>
</robot>

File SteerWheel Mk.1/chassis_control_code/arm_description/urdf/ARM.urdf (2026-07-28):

<?xml version="1.0" encoding="utf-8"?>
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
<robot name="ARM">
  <link name="base_link">
    <inertial>
      <origin xyz="-0.00930961318718291 -2.46017271655133E-05 0.0494776561928281" rpy="0 0 0" />
      <mass value="0.468815276672664" />
      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
    </inertial>
    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
  </link>
  <link name="link1">
    <inertial>
      <origin xyz="-0.00168686014333341 0.00673674839895128 0.0265441272605301" rpy="0 0 0" />
      <mass value="0.215363711819574" />
      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
    </inertial>
    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
  </link>
  <joint name="joint1" type="revolute">
    <origin xyz="-0.01 0 0.048" rpy="0 0 0" />
    <parent link="base_link" />
    <child link="link1" />
    <axis xyz="0 0 1" />
    <limit lower="-135" upper="135" effort="0" velocity="0" />
  </joint>
  <link name="link2">
    <inertial>
      <origin xyz="8.71442817143575E-08 0.0901451144790134 0.00928993112336962" rpy="0 0 0" />
      <mass value="0.129999039828346" />
      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
    </inertial>
    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
  </link>
  <joint name="joint2" type="revolute">
    <origin xyz="-0.01391 0.0039 0.06028" rpy="1.5708 0 0" />
    <parent link="link1" />
    <child link="link2" />
    <axis xyz="0 0 1" />
    <limit lower="-135" upper="135" effort="0" velocity="0" />
  </joint>
  <link name="link3">
    <inertial>
      <origin xyz="2.96709227673442E-09 0.0735487807913097 -0.0151755203710407" rpy="0 0 0" />
      <mass value="0.156195930021367" />
      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
    </inertial>
    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
  </link>
  <joint name="joint3" type="revolute">
    <origin xyz="0 0.18 -0.0001" rpy="0 0 0" />
    <parent link="link2" />
    <child link="link3" />
    <axis xyz="0 0 1" />
    <limit lower="-135" upper="135" effort="0" velocity="0" />
  </joint>
  <link name="link4">
    <inertial>
      <origin xyz="-0.000304948984398003 0.0703542783074806 0.0093402122173849" rpy="0 0 0" />
      <mass value="0.104883177577196" />
      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
    </inertial>
    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
  </link>
  <joint name="joint4" type="revolute">
    <origin xyz="0 0.1471 0" rpy="0 0 0" />
    <parent link="link3" />
    <child link="link4" />
    <axis xyz="0 0 1" />
    <limit lower="-135" upper="135" effort="0" velocity="0" />
  </joint>
  <link name="link5">
    <inertial>
      <origin xyz="0.00243286839430311 0.0174425187399532 -0.0124411516465626" rpy="0 0 0" />
      <mass value="0.0732289914623858" />
      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
    </inertial>
    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
  </link>
  <joint name="joint5" type="revolute">
    <origin xyz="-0.00060707 0.14 0" rpy="0 0 0" />
    <parent link="link4" />
    <child link="link5" />
    <axis xyz="0 0 1" />
    <limit lower="-135" upper="135" effort="0" velocity="0" />
  </joint>
</robot>

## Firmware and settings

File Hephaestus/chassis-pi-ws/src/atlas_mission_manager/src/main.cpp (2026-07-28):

#include <memory>

#include <rclcpp/rclcpp.hpp>

#include "atlas_mission_manager/mission_manager_node.hpp"

int main(int argc, char** argv) {
  rclcpp::init(argc, argv);
  auto node = std::make_shared<atlas_mission_manager::MissionManagerNode>();
  rclcpp::executors::MultiThreadedExecutor executor;
  executor.add_node(node);
  executor.spin();
  node->prepare_shutdown();
  executor.remove_node(node);
  node.reset();
  rclcpp::shutdown();
  return 0;
}

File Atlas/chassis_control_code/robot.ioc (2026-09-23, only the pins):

Mcu.UserName=STM32H723VGTx
PA10.Signal=USART1_RX
PA13(JTMS/SWDIO).Signal=DEBUG_JTMS-SWDIO
PA14(JTCK/SWCLK).Signal=DEBUG_JTCK-SWCLK
PA15(JTDI).GPIO_Label=USER_KEY
PA15(JTDI).Signal=GPIO_Input
PA2.Signal=GPIO_Output
PA5.Signal=SPI6_SCK
PA7.Signal=SPI6_MOSI
PA9.Signal=USART1_TX
PB13.Signal=SPI2_SCK
PB5.Signal=FDCAN2_RX
PB6.Signal=FDCAN2_TX
PC0.GPIO_Label=ACC_CS
PC0.Signal=GPIO_Output
PC1.Signal=SPI2_MOSI
PC12.Signal=UART5_TX
PC13.GPIO_Label=CAN1_EN
PC13.Signal=GPIO_Output
PC14-OSC32_IN.GPIO_Label=CAN2_EN
PC14-OSC32_IN.Signal=GPIO_Output
PC15-OSC32_OUT.GPIO_Label=IO5V_EN
PC15-OSC32_OUT.Signal=GPIO_Output
PC2_C.Signal=SPI2_MISO
PC3_C.GPIO_Label=GYRO_CS
PC3_C.Signal=GPIO_Output
PD0.Signal=FDCAN1_RX
PD1.Signal=FDCAN1_TX
PD2.Signal=UART5_RX
PE0.Signal=UART8_RX
PE1.Signal=UART8_TX
PE10.GPIO_Label=ACC_INT
PE10.Signal=GPXTI10
PE12.GPIO_Label=GYRO_INT
PE12.Signal=GPXTI12
PE13.Signal=GPIO_Output
PE2.Signal=USART10_RX
PE3.Signal=USART10_TX
PE7.Signal=UART7_RX
PE8.Signal=UART7_TX
PE9.Signal=GPIO_Output
PH0-OSC_IN.Signal=RCC_OSC_IN
PH1-OSC_OUT.Signal=RCC_OSC_OUT

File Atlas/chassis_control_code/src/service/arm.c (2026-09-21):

/**
 * @file arm.c
 * @brief 五自由度舵机机械臂服务层实现
 */
#include "arm.h"

#include <string.h>

// ! ========================= 变 量 声 明 ========================= ! //

/**
 * @brief 机械臂服务内部可变运行实例
 */
static Arm s_arm = { 0 };
/**
 * @brief 机械臂服务对外只读快照
 */
static Arm s_arm_view = { 0 };
/* The Idle/Fault stop path disables servo torque. A new target must re-enable
 * torque after the goal registers are updated. */
static bool s_torque_enabled = false;

/**
 * @brief 机械臂服务状态刷新失败的循环保护
 *
 * 如果连续多次刷新失败, 则会暂时停止刷新尝试;
 * 直到下一次成功刷新后才会恢复正常刷新
 */
static uint8_t s_refresh_fallback_index = 0u;

/**
 * @brief 机械臂服务状态刷新失败的循环保护阈值
 *
 * 如果连续刷新失败次数超过该阈值, 则会触发循环保护机制
 */
static bool s_refresh_fallback_seen[ARM_DOF] = { false };

/**
 * @brief 机械臂服务统一接口实例
 */
const struct ArmInterface arm_interface = {
#define X(name, str) .name = ARM_##name,
    { ARM_STATUS_TABLE },
#undef X
    .default_config = arm_default_config,
    .init = arm_init,
    .move_joints = arm_move_joints,
    .move_joint = arm_move_joint,
    .move_servo_zero = arm_move_servo_zero,
    .move_mdh_zero = arm_move_mdh_zero,
    .move_pose = arm_move_pose,
    .move_pose_5d = arm_move_pose_5d,
    .move_position = arm_move_position,
    .move_orientation_2d = arm_move_orientation_2d,
    .move_orientation = arm_move_orientation,
    .stop = arm_stop,
    .enable = arm_enable,
    .fk = arm_fk,
    .ik = arm_ik,
    .is_ready = arm_is_ready,
    .get_arm = arm_get_arm,
    .refresh_current_state = arm_refresh_current_state,
    .get_current_joints = arm_get_current_joints,
    .get_current_pose = arm_get_current_pose,
    .status_str = arm_status_str,
};

// ! ========================= 私 有 函 数 声 明 ========================= ! //

/**
 * @brief 检查服务初始化配置是否合法
 * @param config 初始化配置
 * @return bool `true` 表示配置合法
 */
static bool s_config_is_valid(const ArmConfig* config);
/**
 * @brief 检查关节索引是否合法
 * @param joint_index 关节索引
 * @return bool `true` 表示索引合法
 */
static bool s_joint_index_valid(uint8_t joint_index);
/**
 * @brief 检查关节数组是否合法
 * @param joints 关节数组
 * @return bool `true` 表示数组合法
 */
static bool s_joint_array_valid(const FiveDofArmJointArray* joints);
/**
 * @brief 检查指定关节角是否落在数学模型限位内
 * @param index 关节索引
 * @param q 关节角，单位 rad
 * @return bool `true` 表示在限位内
 */
static bool s_joint_in_limit(uint8_t index, float q);
/**
 * @brief 检查实物默认零位关节数组是否合法
 * @param joints 零位关节数组
 * @return bool `true` 表示配置合法
 */
static bool s_servo_zero_valid(const FiveDofArmJointArray* joints);

/**
 * @brief 在临时任务行约束下执行一次 IK，并在退出前恢复原任务配置
 * @param target 目标位姿
 * @param joints 输出关节解
 * @param seed IK 初始种子
 * @param task 临时任务行配置；传入 `NULL` 表示沿用当前配置
 * @return ArmStatus 服务状态码
 */
static ArmStatus s_ik_with_task(const FiveDofArmPose* target, FiveDofArmJointArray* joints,
                                const FiveDofArmJointArray* seed, const SerialArmTaskInfo* task);
/**
 * @brief 向舵机层发送一组关节目标
 * @param joints 目标关节数组，单位 rad
 * @param speed_rad_s 目标速度，单位 rad/s
 * @return ArmStatus 服务状态码
 */
static ArmStatus s_send_joints_to_servo(const FiveDofArmJointArray* joints, float speed_rad_s);
/**
 * @brief 用最新目标关节和位姿结果刷新目标缓存
 * @param joints 最新目标关节数组
 * @param pose 最新目标末端位姿
 * @return ArmStatus 服务状态码
 */
static ArmStatus s_update_target_state(const FiveDofArmJointArray* joints, const FiveDofArmPose* pose);
/**
 * @brief 用最新关节和位姿结果刷新服务缓存
 * @param joints 最新关节数组
 * @param pose 最新末端位姿
 * @return ArmStatus 服务状态码
 */
static ArmStatus s_update_current_state(const FiveDofArmJointArray* joints, const FiveDofArmPose* pose);
/**
 * @brief 同步内部运行实例到对外只读快照
 */
static void s_sync_view(void);
/**
 * @brief 获取当前用于连续规划的参考关节角
 * @param joints 输出参考关节角
 * @return ArmStatus 服务状态码
 */
static ArmStatus s_get_reference_joints(FiveDofArmJointArray* joints);
/**
 * @brief 获取当前用于连续规划的参考末端位姿
 * @param pose 输出参考末端位姿
 * @return ArmStatus 服务状态码
 */
static ArmStatus s_get_reference_pose(FiveDofArmPose* pose);

/**
 * @brief 解析最终使用的运动速度
 * @param speed_rad_s 外部请求速度，单位 rad/s
 * @return float 实际使用速度，单位 rad/s
 */
static float s_resolve_speed(float speed_rad_s);

// ! ========================= 接 口 函 数 实 现 ========================= ! //

/**
 * @brief 获取默认初始化配置
 * @return ArmConfig 默认配置
 */
ArmConfig arm_default_config(void) {
    ArmConfig config;
    memset(&config, 0, sizeof(config));

    config.servo_interface = NULL;
    config.stop_servo = NULL;
    config.enable_servo = NULL;
    config.has_kinematic_model = false;
    for(uint8_t i = 0u; i < ARM_DOF; i++) {
        config.servo_id[i] = i;
        config.servo_zero_joints.q[i] = 0.0f;
    }
    config.servo_zero_joints.dof = ARM_DOF;
    config.default_speed_rad_s = 3.14f;
    config.auto_move_servo_zero = true;
    return config;
}

/**
 * @brief 初始化机械臂服务
 * @param config 初始化配置
 * @return ArmStatus 服务状态码
 */
ArmStatus arm_init(const ArmConfig* config) {
    ArmStatus ret;
    FiveDofArmJointArray mdh_zero;

    if(s_config_is_valid(config) == false) {
        return ARM_INVALID_PARAM;
    }

    memset(&s_arm, 0, sizeof(s_arm));
    s_torque_enabled = false;
    memset(s_refresh_fallback_seen, 0, sizeof(s_refresh_fallback_seen));
    s_refresh_fallback_index = 0u;
    s_arm.config = *config;
    if(s_arm.config.default_speed_rad_s <= 0.0f) {
        s_arm.config.default_speed_rad_s = 3.14f;
    }

    if(five_dof_arm.init_with_model(&config->kinematic_model) != SERIAL_ARM_STATUS_SUCCESS) {
        return ARM_KINEMATICS_FAILED;
    }

    if(five_dof_arm.get_mdh_zero(&mdh_zero) != SERIAL_ARM_STATUS_SUCCESS) {
        return ARM_KINEMATICS_FAILED;
    }
    if(five_dof_arm.fk(&mdh_zero, &s_arm.current_pose) != SERIAL_ARM_STATUS_SUCCESS) {
        return ARM_KINEMATICS_FAILED;
    }
    s_arm.target_joints = mdh_zero;
    s_arm.target_pose = s_arm.current_pose;
    s_arm.target_valid = true;
    s_arm.current_joints = mdh_zero;
    s_arm.current_valid = false;
    s_arm.initialized = true;
    s_sync_view();

    if(config->auto_move_servo_zero) {
        ret = arm_move_servo_zero(config->default_speed_rad_s);
        if(ret != ARM_OK) {
            return ret;
        }
    }

    return ARM_OK;
}

/**
 * @brief 按关节数组下发整机目标
 * @param joints 目标关节角，单位 rad
 * @param speed_rad_s 目标速度，单位 rad/s
 * @return ArmStatus 服务状态码
 */
ArmStatus arm_move_joints(const FiveDofArmJointArray* joints, float speed_rad_s) {
    FiveDofArmPose pose;
    ArmStatus ret;

    if(s_arm.initialized == false)
        return ARM_NOT_INITIALIZED;
    if(s_joint_array_valid(joints) == false)
        return ARM_INVALID_PARAM;

    for(uint8_t i = 0u; i < ARM_DOF; i++) {
        if(s_joint_in_limit(i, joints->q[i]) == false) {
            return ARM_OUT_OF_LIMIT;
        }
    }

    if(five_dof_arm.fk(joints, &pose) != SERIAL_ARM_STATUS_SUCCESS) {
        return ARM_KINEMATICS_FAILED;
    }

    ret = s_send_joints_to_servo(joints, s_resolve_speed(speed_rad_s));
    if(ret != ARM_OK)
        return ret;

    if(!s_torque_enabled) {
        ret = arm_enable();
        if(ret != ARM_OK)
            return ret;
    }

    return s_update_target_state(joints, &pose);
}
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

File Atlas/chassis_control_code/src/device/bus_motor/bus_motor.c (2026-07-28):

#include "bus_motor.h"

// ! ========================= 变 量 声 明 ========================= ! //

/**
 * @brief 当前绑定的具体电机实例
 */
const BusMotorInterface* bus_motor_instance = 0;

// ! ========================= 接 口 函 数 实 现 ========================= ! //

/**
 * @brief 绑定具体电机实例
 */
BusMotorStatus bus_motor_set_instance(const BusMotorInterface* instance) {
    if(instance == 0) {
        return MOTOR_STATUS_INVALID_PARAM;
    }

    bus_motor_instance = instance;
    return MOTOR_STATUS_OK;
}

/**
 * @brief 初始化当前绑定的电机实例
 */
BusMotorStatus bus_motor_init(const BusMotorConfig* config) {
    if(bus_motor_instance == 0 || bus_motor_instance->init == 0) {
        return MOTOR_STATUS_NO_INSTANCE;
    }

    return bus_motor_instance->init(config);
}

/**
 * @brief 将状态码转换为常量字符串
 */
const char* bus_motor_status_str(BusMotorStatus status) {
    if(bus_motor_instance != 0 && bus_motor_instance->status_str != 0) {
        return bus_motor_instance->status_str(status);
    }

    switch(status) {
#define X(name, value) case MOTOR_STATUS_##name: return #name;
        MOTOR_STATUS_TABLE
#undef X
        default: return "UNKNOWN";
    }
}

/**
 * @brief 将模式值转换为常量字符串
 */
const char* bus_motor_mode_str(BusMotorMode mode) {
    if(bus_motor_instance != 0 && bus_motor_instance->mode_str != 0) {
        return bus_motor_instance->mode_str(mode);
    }

    (void)mode;
    return "UNKNOWN";
}

/**
 * @brief 使能电机
 */
BusMotorStatus bus_motor_enable(uint16_t id) {
    if(bus_motor_instance == 0 || bus_motor_instance->enable == 0) {
        return MOTOR_STATUS_NO_INSTANCE;
    }

    return bus_motor_instance->enable(id);
}

/**
 * @brief 失能电机
 */
BusMotorStatus bus_motor_disable(uint16_t id) {
    if(bus_motor_instance == 0 || bus_motor_instance->disable == 0) {
        return MOTOR_STATUS_NO_INSTANCE;
    }

    return bus_motor_instance->disable(id);
}

/**
 * @brief 切换电机模式
 */
BusMotorStatus bus_motor_switch_mode(uint16_t id, BusMotorMode mode) {
    if(bus_motor_instance == 0 || bus_motor_instance->switch_mode == 0) {
        return MOTOR_STATUS_NO_INSTANCE;
    }

    return bus_motor_instance->switch_mode(id, mode);
}

/**
 * @brief 设定目标位置
 */
BusMotorStatus bus_motor_set_pos(uint16_t id, float position) {
    if(bus_motor_instance == 0 || bus_motor_instance->set_pos == 0) {
        return MOTOR_STATUS_NO_INSTANCE;
    }

    return bus_motor_instance->set_pos(id, position);
}

/**
 * @brief 设定目标速度
 */
BusMotorStatus bus_motor_set_spd(uint16_t id, float speed) {
    if(bus_motor_instance == 0 || bus_motor_instance->set_spd == 0) {
        return MOTOR_STATUS_NO_INSTANCE;
    }

    return bus_motor_instance->set_spd(id, speed);
}

/**
 * @brief 设定目标位置和速度
 */
BusMotorStatus bus_motor_set_pos_vel(uint16_t id, float position, float speed) {
    if(bus_motor_instance == 0 || bus_motor_instance->set_pos_vel == 0) {
        return MOTOR_STATUS_NO_INSTANCE;
    }

    return bus_motor_instance->set_pos_vel(id, position, speed);
}

/**
 * @brief 设定目标扭矩或等效前馈
 */
BusMotorStatus bus_motor_set_tor(uint16_t id, float torque) {
    if(bus_motor_instance == 0 || bus_motor_instance->set_tor == 0) {
        return MOTOR_STATUS_NO_INSTANCE;
    }

    return bus_motor_instance->set_tor(id, torque);
}

/**
 * @brief 设定位置环 PD 参数
 */
BusMotorStatus bus_motor_set_pd(uint16_t id, float kp, float kd) {
    if(bus_motor_instance == 0 || bus_motor_instance->set_pd == 0) {
        return MOTOR_STATUS_NO_INSTANCE;
    }

    return bus_motor_instance->set_pd(id, kp, kd);
}

/**
 * @brief 主动请求并更新反馈缓存
 */
BusMotorStatus bus_motor_update_feedback(uint16_t id, BusMotorFeedback* feedback) {
    if(bus_motor_instance == 0 || bus_motor_instance->update_feedback == 0) {
        return MOTOR_STATUS_NO_INSTANCE;
    }

    return bus_motor_instance->update_feedback(id, feedback);
}

/**
 * @brief 获取最近位置反馈
 */
float bus_motor_get_pos(uint16_t id) {
    if(bus_motor_instance == 0 || bus_motor_instance->get_pos == 0) {
        return 0.0f;
    }

    return bus_motor_instance->get_pos(id);
}

/**
 * @brief 获取最近速度反馈
 */
float bus_motor_get_spd(uint16_t id) {
    if(bus_motor_instance == 0 || bus_motor_instance->get_spd == 0) {
        return 0.0f;
    }

    return bus_motor_instance->get_spd(id);
}

/**
 * @brief 获取最近扭矩反馈
 */
float bus_motor_get_tor(uint16_t id) {
    if(bus_motor_instance == 0 || bus_motor_instance->get_tor == 0) {
        return 0.0f;
    }

    return bus_motor_instance->get_tor(id);
}

/**
 * @brief 停止电机
 */
BusMotorStatus bus_motor_stop(uint16_t id) {
    if(bus_motor_instance == 0 || bus_motor_instance->stop == 0) {
        return MOTOR_STATUS_NO_INSTANCE;
    }

    return bus_motor_instance->stop(id);
}

/**
 * @brief 制动电机
 */
BusMotorStatus bus_motor_brake(uint16_t id) {
    if(bus_motor_instance == 0 || bus_motor_instance->brake == 0) {
        return MOTOR_STATUS_NO_INSTANCE;
    }

    return bus_motor_instance->brake(id);
}

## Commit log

2026-06-05 core: 初代轮式机器人代码完成
    [ARM.csv, ARM.urdf, base_link.STL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]
2026-06-08 Atlas导航配置和仿真
    包含 Atlas 导航系统完整配置和仿真代码。
    更新 .gitignore 忽略 docs/ 和 .vscode/ 目录。
    [LFd_Link.STL, LFs_Link.STL, LRd_Link.STL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]
2026-06-09 core(chassis): 更换底盘轮径
2026-06-09 core(Atlas): 更新 Atlas 底盘 MCU 代码
    [ARM.csv, ARM.urdf, base_link.STL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]
2026-06-12 feat(k_vx): 调 k_vx 参数以适应新车
2026-06-12 feat(k_vy): 调节 k_vy 参数
2026-06-12 feat(k_vx, k_vy): 更新底盘 vx vy 偏移
2026-06-13 feat(kalman): 卡尔曼融合算法, 融合底盘+IMU数据获取三轴角度+三轴里程计
2026-06-13 feat(odom): 组合底层与算法层, 提供 odom 接口
2026-06-13 docs(odom): 里程计相关注释补充
2026-06-13 feat(odom): 增加静止检测, 减小零飘
2026-06-13 feat(arm_model): 更新新版机械臂, 但是 dh 参数还是有点问题
    [ARM.csv, ARM.urdf, Atlas.csv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]
2026-06-13 fix(arm_model): 修正 MDH 参数和输入方向
2026-06-13 feat(uart7): 修改机械臂串口配置
2026-06-13 feat(arm): 接入机械臂成功, fk/ik 测试成功
2026-06-13 feat(remote): 配置机械臂遥控
2026-06-14 feat(remote): 新增末端控制 perf(remote): 优化机械臂控制参数
2026-06-14 refactor(remote): 优化控制任务逻辑，提升代码清晰度
2026-06-14 refactor(remote/entry): 优化了部分逻辑
2026-06-14 perf(entry): 分配各任务频率
2026-06-14 feat(ft_scs): 优化为批量读写接口, 减少主循环中的 ACK 等待次数
2026-06-14 feat(protocol_parser): 优化 protocol_parser.*
2026-06-14 feat(uart10): 新增串口10用于双机通信
2026-06-20 refactor: 优化比赛代码, 整理出通用架构和代码框架, 删除冗余代码, 以便后续维护和开发
2026-06-20 docs(plan): 新增计划
2026-06-21 feat(app_control): 节流一次性动作的日志报错
2026-06-21 perf(app_fsm): 优化错误处理
2026-06-21 fix(fault): 修复了遥控器错误恢复手势
2026-06-21 feat(comms): 解耦通信服务
2026-06-21 feat(comms); 完成通信服务
2026-06-21 docs(comms): 更新通信协议
2026-06-21 perf(heart): 修改 pc/pi 在线超时时间
2026-06-21 remove(asrpro): 去掉 asrpro 驱动
2026-06-21 perf(hz): 优化控制频率
2026-06-21 refactor(comms): 分离 imu/odom 周期帧
2026-06-22 feat(ros): ros 端桥接节点
2026-06-22 docs(README): 更新 README
2026-06-22 feat(teleop): 更新 pc 与 mcu 之间的遥操作
2026-06-22 feat(comms): 更新 PI PC 通信协议
2026-06-22 refactor(docs): 移动 Atlas/chassis-pi-ws/docs/comms_protocol.md 到 docs/comms_protocol.md
2026-06-22 feat(pi): 更新 pi 的通信协议解析
2026-06-22 docs(README): 更新 PI 的 README
2026-06-23 docs(teleop): 更新脚本说明
2026-06-23 config(teleop): 更新 teleop 配置
2026-06-23 feat(teleop): 更新基本映射
2026-06-23 feat(teleop): 脚本会打印当前角度即收到的日志
2026-06-30 docs(README): 更新 PI 的日志说明
2026-07-04 config(PI): pi 端默认使用 ch340 为 ttyUSB
2026-07-04 config(comms): MCU 和 PI 的通信波特率改为 1M
2026-07-04 fix(comms): 修复 MCU 端集中发送导致吞帧问题, 修复 PI 端 CRC 校验错误一次丢失两帧问题
    [pi_comms.c, pi_comms.h]
2026-07-04 fix(CMake): 修复 cmake 配置，移除测试相关内容
2026-07-04 perf(mcu): 优化 mcu 日志 perf(pi): 优化 pi 通信的 crc 校验环节 perf(comms): 优化通信协议解析器，支持 CRC-16-CCITT 恢复, 优化 pi 串口独占启动
2026-07-04 docs(log): 日志加入分隔线，便于阅读
2026-07-04 docs(log): 优化日志分割线
2026-07-05 feat(app_status): 重新分配槽位, 优化数据流, 确保通信稳定性
2026-07-05 feat(pi): 更新 pi 端协议, 支持控制机械臂
2026-07-05 feat(mcu): 更新 MCU 端协议, 新增对 PI 端信息的解析
2026-07-05 feat(gui): 遥操作 GUI
2026-07-05 fix(gui): 修复显示 bug feat(gui): 新增超时机制
2026-07-05 feat(gui): 尝试使用 PyInstaller 打包 GUI 应用
2026-07-05 docs(pi): 更新 PI README
2026-07-05 fix(pi): 修复 pi 影响 MCU 同步反馈的问题
2026-07-05 feat(comms): 更新 arm_state 协议, 支持完整的位姿数据和四元数校验
2026-07-05 fix(topic): 修复话题错误
2026-07-05 fix(comms): 缩减 arm 帧, 防止桥接侧解析失败
    [pi_comms.c]
2026-07-06 feat(handeye): 手眼标定工具
2026-07-06 feat(arm): 新增虚拟机械臂支持
2026-07-06 fix(mcu_comm_bridge): 修复时间戳倒退的 bug
2026-07-06 fix(mcu_comm_bridge): 修复时间戳相同的 bug
2026-07-06 perf(imu): imu 优化为实时 dt 积分
2026-07-06 feat(dji_motor): 适配 M2006 + C610 型号，新增 driver_config 透传
2026-07-06 feat(odom): 自定义 IMU YAW 率缩放因子
2026-07-06 docs(log): 删除调试 Log
2026-07-07 feat(mcu): 新增自动启动事件锁存功能，允许在特定条件下触发自动启动，并在需要时通过远程手势清除锁存状态。
2026-07-07 feat(mcu_comm_bridge): 新增 `/mcu/status` 与 `/mcu/auto_task_event` 话题，桥接 MCU 状态与自动任务事件
2026-07-07 docs(comms_protocol): 更新协议文档
2026-07-07 docs(chassis_control_code): 新增 README
2026-07-07 feat(pi): 上报 MCU 任务的 ros2 接口
2026-07-08 feat(pi): Pi 端状态机初步实现
2026-07-08 docs(chassis): 更新注释
2026-07-08 feat(suction): 新增吸盘继电器控制模块及组装接口
2026-07-08 feat(app_control): 接入 pc 遥操作时的吸盘动作
2026-07-08 feat(entry): 初始化 suction 模块
2026-07-08 docs(chassis_control_code): 更新遥控手势
2026-07-09 feat(nav): 删除原导航系统
    [LFd_Link.STL, LFs_Link.STL, LRd_Link.STL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]
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2026-07-09 fix(pi): 修复日志打印错误
2026-07-09 fix(pi): 修复类型推导错误
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2026-07-09 feat(mission): B 区策略算法, 防止 joint0 大角度旋转导致撞击龙门架
2026-07-09 fix(nav): 优化伪导航步进算法
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2026-07-09 revert(arm): 恢复原来可以完成维持原姿态的 arm 解算策略
    [arm.c]
2026-07-10 feat(Atlas): 更新睿抗全自动区
    [robot_description.urdf]
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2026-07-27 feat(Hephaestus): 第二辆机器人，更新机械臂模型
    [Atlas.csv, Atlas.urdf, LFd_Link.STL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]
2026-07-28 feat(asrpro): 简化 asrpro 协议和主程序
    [ARM.csv, ARM.urdf, Atlas.csv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]
2026-07-29 featatlas_asrpro): 更新 asrpro 程序
2026-08-10 feat(asrpro+mcu): asrpro 改接到 mcu UART8，简化 MCU ↔ ASRPro 协议
2026-08-10 fix(pi): 删除老旧功能包
2026-08-20 core(yasmin): 新建 mission_yasmin 包骨架，包含 launch、config、scripts 和 src 目录
2026-08-22 feat(runtime): 新增 Atlas YASMIN 运行时框架，提供任务执行、状态管理和后端交互功能
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2026-08-22 feat(yaml): 完成了对任务路线 yaml 文件的解析和加载功能
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2026-08-31 feat(asrpro): 完成 asrpro 代码
2026-08-31 feat(mcu): 优化 AUTO gesture 识别逻辑
2026-08-31 feat(vision): 替换成新的 vision-system
    [robot_params.yaml]
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2026-09-04 feat(vision): wire competition vision backend
2026-09-04 feat(nav): 接入导航后端 feat(bringup): 接入顶层比赛配置 todo(yaml): 比赛配置文件待配置
2026-09-04 docs(README): 更新 pi 端 README
2026-09-05 docs(README): 更新 README 中的视觉和手眼标定说明
2026-09-05 docs(README): 完善 README.md，增加 PC 端 App 说明和 Pi 端依赖安装
2026-09-05 chore(yasmin): 解除 yasmin .git 仓库属性，需要整个 cv 进 pi 中
2026-09-06 chore(usart): swap uart8 and uart10 for PI and ASR comms
    [robot.ioc, stm32_hal_uart.c]
2026-09-09 config(competition-nav): 完成 A 半场的地图导入与标点，先测试
2026-09-11 docs(yaml): 新增对 competition.yaml 的详细注释
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2026-09-11 chore(rviz2): rviz2/ 文件夹需要有文件进行占位，否则 git 不会提交空文件夹
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2026-09-11 feat(nav): 新增激光绝对对齐 + Odom 直达的原点导航后端
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2026-09-12 feat(config): 修改了 A 区点位
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2026-09-16 fix:competition: 修复机械臂超时启动。状态机问题未修复
2026-09-17 feat(asrpro): 更新 Hephaestus 的 asrpro
2026-09-17 feat(chassis_control_code): 更新 Hephaestus MCU
2026-09-18 Bug: 未修复导航无法重定位问题
2026-09-18 fix(auto_zone): 修复自动区不会在启动定位时等待地图约束的错误
2026-09-18 fix(auto_zone): 修复自动区重定位问题 feat(pick_up): 优化货物区流程
2026-09-19 fix(arm): 约束机械臂姿态
2026-09-19 fix(competition): 智能分拣区判断逻辑修复
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2026-09-19 merge(fix-bmap): 合并两个版本
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2026-09-21 fix(arm): 修复机械臂在某些姿态下无法到位的问题
2026-09-22 fix(arm): 关节到位判断按 2π 归一化，修复 zero 位 q2 回绕导致机械臂无法启动
    zero 位姿 q2 目标 ≈ 2π(6.28)，舵机反馈会回绕到 0 附近；_wait_joint_target
    之前用 abs(a-b) 直接相减，|0-6.28|=6.28rad 远超 joint_tolerance_rad，
    机械臂实际已到位却判超时、任务失败，表现成"机械臂无法启动"。
    - 关节角比较改为最短弧差：abs((a-b+π) % 2π - π)
    - _wait_joint_target 每 5s 打印 target/actual/error 诊断，并区分
    "无新鲜反馈"(MCU 停流) 与 "到位未收敛" 两种卡死
    - 新增 2π 回绕到位、真实超差仍超时两组回归测试
2026-09-22 fix(arm): 放宽关节到位容差 0.06→0.10rad，与 handeye_bridge 5° 轴容差同级
    SetArmJoints 命名位姿(zero/sorting/nav)的到位判断原为每关节 3.4°，
    比 vision 后端"位置+5°轴"更严；舵机回程差/微抖会把已到位误判成超时。
    放宽到 ≈5.7°，TCP 位置仍有 pose_validation_tolerance_m=0.08 二次把关。
2026-09-23 feat(app_control): add suction control for remote arm eef
2026-09-23 fix(compre):修复自动区顺序问题，还需要解决货物区逻辑。
2026-09-24 fix(arm):可以基础完成要求，导航和观察区需要改进
2026-09-24 fix(compition):可以基本完成内容
2026-09-24 fix(compitition):修复导航，很大程度完成比赛
2026-09-24 fix(compitition):提高速度和优化导航
2026-09-24 refactor(pi): 将 pi 中正确代码替换回本地, 上一个 merge 被 claude 修错了
